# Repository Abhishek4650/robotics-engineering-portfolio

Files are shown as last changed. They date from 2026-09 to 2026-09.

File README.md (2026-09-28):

# Robotics Engineering Portfolio — Abhishek Ray

**6-DOF robot arms: from the kinematics maths, to a mechanical design, to servos moving on a real bus.**

ROS 2 Jazzy · Python · analytical kinematics · parametric CAD · embedded serial-bus servos

I build the whole stack rather than gluing libraries together: the forward kinematics,
Jacobian and IK solvers here are derived and implemented from first principles, then
**verified numerically** against an independent library and against the URDF itself.

---

## Project 1 — Sine-wave trajectory tracing on a myCobot 280

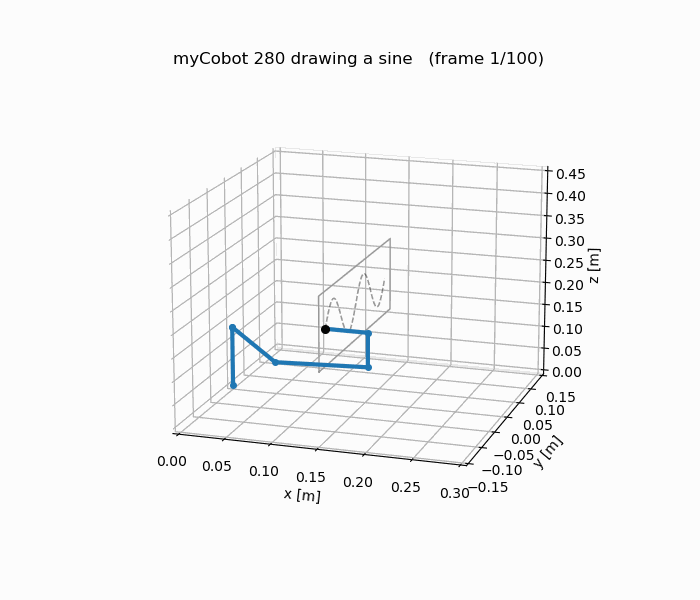
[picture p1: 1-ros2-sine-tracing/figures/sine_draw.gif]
myCobot 280 tracing a sine wave in RViz


A ROS 2 package that drives a 6-DOF arm along a sine wave on a surface, holding the pen
**normal to that surface** throughout.

| | |
| --- | --- |
| **Kinematics** | Modified (Craig) DH forward kinematics, written from scratch |
| **Jacobian** | Velocity propagation, link by link |
| **IK** | Damped least squares, with a tuned damping sweep |
| **Verification** | FK matches the URDF to **~1e-15 m**; Jacobian matches finite differences to **2.5e-7**; cross-checked against `ikpy` |
| **Runtime** | Precomputed trajectory streamed to `/joint_states` at 30 Hz; `robot_state_publisher` → TF → RViz |
| **Feedback** | A second node accumulates the *actually drawn* line from TF, so target (green) and achieved (red) are visible side by side |

→ [`1-ros2-sine-tracing/`](1-ros2-sine-tracing) · [package README](1-ros2-sine-tracing/README.md)

**Why it's not trivial:** a naive IK solution flips the wrist mid-stroke or drifts off the
plane. Constraining the tool orientation while tracking a moving Cartesian target is where
the DLS damping term and the seeding strategy actually matter.

---

## Project 2 — ARM-450: a clean-sheet 6-DOF arm, designed to a hard mass budget

*The first concept. Its successor, rev I.1, the version sent to the printer, is
[Project 6](#project-6--arm-450-rev-i1-the-printable-arm-verified-part-against-part).*

<p align="center">
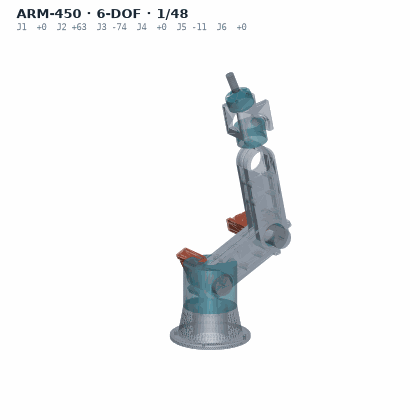
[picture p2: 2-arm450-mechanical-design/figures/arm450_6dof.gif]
ARM-450 six degrees of freedom

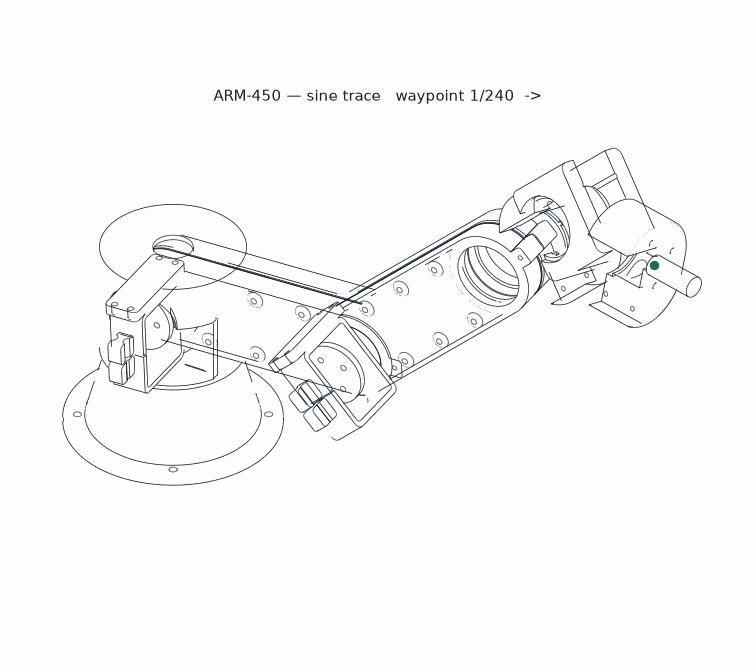
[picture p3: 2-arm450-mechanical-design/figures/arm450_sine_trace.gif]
ARM-450 tracing a sine

</p>

A complete arm designed from nothing — geometry, structure, bearings, fasteners, thermals,
print plan — driven entirely by **parametric Python**, not by hand-modelling in a GUI.
Every dimension comes from `design_params.py`; the URDF, the STEP/STL exports, the
drawings and the reports all regenerate from it.

| Requirement | Result |
| --- | --- |
| Overall length ≤ 450 mm | **450.0 mm** |
| Mass ≤ 1450 g | **1365 g** (85 g headroom) |
| Degrees of freedom | **6**, all with real, sourced hardware |
| Horizontal reach | 360 mm |
| Reachable workspace | **190 litres**, no dead zone |
| Printed parts | 19 pieces, 624 g |
| Sine tracing on the design | **240/240 waypoints, 0.014 mm RMS, 0 collisions** |
| Pre-print gate | **60 checks passed, 0 warnings, 0 failures** |
| STEP B-rep geometry audit | **52 features verified, 0 outstanding** |

**Engineering done here:** joint bearing selection and clearance fits, stress and FEA runs,
compliance budget, creep/fatigue check, servo thermal analysis, interference and mate
checking on the real B-rep, topology and geometry optimisation, slicing/print planning,
and a full bill of materials with sourcing.

The audit caught three defects that would each have wasted a print run — including three
bearing seats that did not physically exist in the solid.

**It is not only drawings — the arm runs.** [`ros2/arm450_description`](2-arm450-mechanical-design/ros2/arm450_description)
is the generated URDF plus meshes, and [`ros2/arm450_sine`](2-arm450-mechanical-design/ros2/arm450_sine)
drives the sine trajectory on it: the design is loaded into ROS 2 and moved, so the geometry
is checked by simulation and not only by the drawings that produced it.

→ [`2-arm450-mechanical-design/`](2-arm450-mechanical-design) ·
[Summary](2-arm450-mechanical-design/SUMMARY.md) ·
[Full report](2-arm450-mechanical-design/REPORT.md) ·
[Drawings](2-arm450-mechanical-design/output) ·
[BOM](2-arm450-mechanical-design/BUY.md)

---

## Project 3 — Hardware bring-up: ESP32 + STS3215 serial-bus servos

Getting a real arm to move, working up from a dead bus.

- **Read-only diagnostics first.** [`scs_diag.py`](3-hardware-esp32-servo/arm_demo/scs_diag.py)
  pings each servo ID and dumps registers using only `PING` and `READ` — no motion command
  is issued until the bus is understood.
- **Protocol reverse-engineering.** Determines the servo family (SC vs ST) from the model
  register, because the two families differ in **units and endianness**; getting this wrong
  drives joints to the wrong angle.
- **Opening the port without resetting the board.** The ESP32 resets on DTR/RTS pulse, which
  drops it out of `SERIAL_FORWARDING` mode — so the port is opened with those lines
  suppressed. This was the actual blocker that stopped the arm moving.
- **Then motion:** single-joint moves, continuous oscillation with logged runs, and finally
  the same sine trajectory from Project 1 streamed to the physical arm.

Stack: Waveshare ESP32 driver board → USB `SERIAL_FORWARDING` bridge → 1 Mbps servo bus → STS3215 servos.

→ [`3-hardware-esp32-servo/`](3-hardware-esp32-servo) · [operating guide (PDF)](3-hardware-esp32-servo/robotic_motion/Robotic_Motion_Guide.pdf) · [run logs](3-hardware-esp32-servo/robotic_motion/logs)

---

## Project 4 — myCobot RViz demo (earlier iteration)

The first working version: offline `ikpy` IK over the official M5 URDF, streamed as
`/joint_states` for RViz. Kept because it shows the progression from *using* an IK library
to *writing* the solver in Project 1.

→ [`4-mycobot-rviz-demo/`](4-mycobot-rviz-demo)

---

## Project 5 — How I got here: the ROS 2 learning progression

I started ROS 2 from zero. The six packages that led to Project 1 are kept **in order and
unedited** — publisher/subscriber, forward kinematics, a first sine attempt, a rewrite after
that attempt drifted, a modular restructure, then the verified solver.

Steps 3 and 4 exist because step 3 was wrong: the arm drifted off the plane, so I wrote a
separate FK test to isolate whether the fault was in the kinematics or the solver. It was in
the kinematics. The 1e-15 m agreement in the finished package is a direct consequence.

→ [`5-ros2-learning-progression/`](5-ros2-learning-progression)

---

## Project 6 — ARM-450 rev I.1: the printable arm, verified part against part

<p align="center">
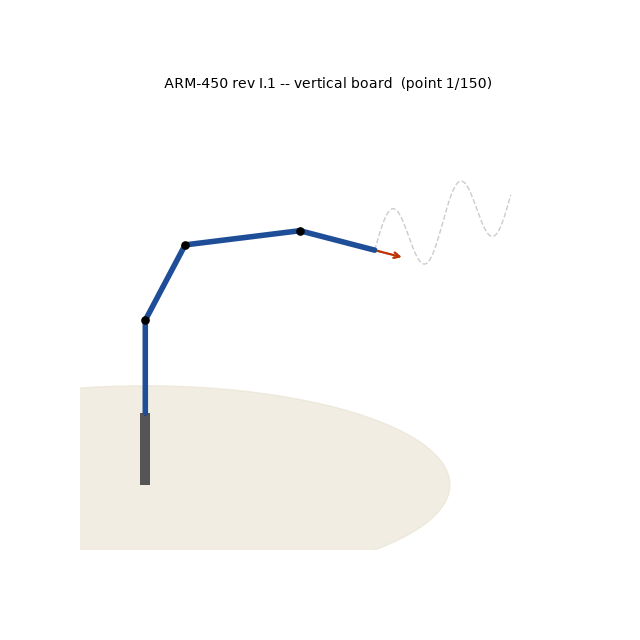
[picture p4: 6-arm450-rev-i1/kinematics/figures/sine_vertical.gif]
ARM-450 rev I.1 tracing a sine on a board

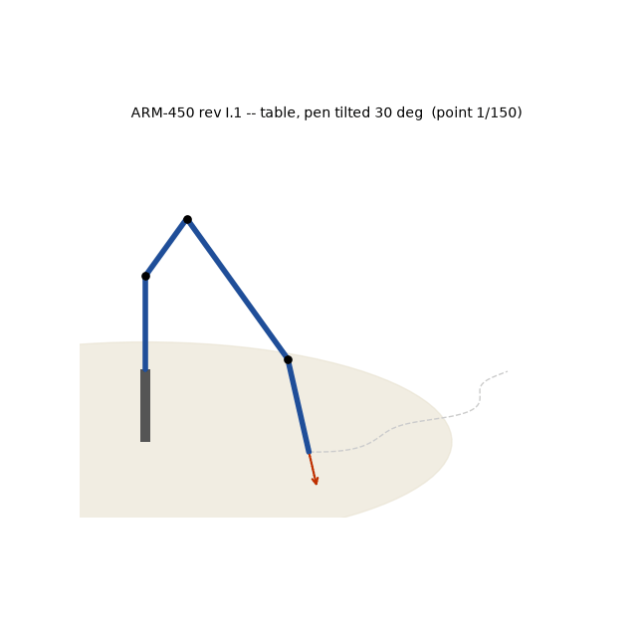
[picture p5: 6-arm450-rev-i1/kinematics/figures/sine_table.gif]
ARM-450 rev I.1 tracing a sine on a table

</p>

The second generation of ARM-450, released for printing: six ST3215 servos, 27 print files
(33 pieces) and 114 screws. The whole release is checked **on the exported 3D geometry**:

- parts may touch only on designed faces, and any other overlap is measured as a boolean volume;
- the official servo model, bearings and every fastener are modelled as solids;
- a hex key must reach every screw at its build step;
- every servo must come out, and every bus plug must go in, with the arm assembled;
- each joint has a proven cable route;
- every glued feature must join over its full section.

All 25 check stages are at 0 failures, and each has its own log.

| | |
| --- | --- |
| **Release** | STL print set + fit-test coupons, STEP parts and assembly, URDF, a Fusion 360 script per part (editable timeline → `.f3d`), SolidWorks macro, 24-step base-to-flange assembly guide |
| **Kinematics** | DH table **derived from the servo axes measured on the CAD**; FK = CAD = URDF to 3e-13 mm; closed-form Pieper IK (8 branches, 0.18 ms) vs DLS / pinv / J-transpose / LM / ikpy |
| **Workspace finding** | The pen can never point straight down: J2 + J3 + J5 give 172.5° of pitch, not 180°. On a table the pen must tilt. |
| **Timing** | Resolved-rate tracking of a 5-D pen task, with the free roll used in the null space; board sine at ~82 mm/s with the servos at half their rating; encoder floor ~0.9 mm |
| **Status** | Print verdict GREEN from the CAD checks; not yet built and measured |

→ [`6-arm450-rev-i1/`](6-arm450-rev-i1) · [README](6-arm450-rev-i1/README.md) ·
[audit report](6-arm450-rev-i1/release/PDF/ARM450_AUDIT_REPORT.pdf) ·
[assembly guide](6-arm450-rev-i1/release/PDF/ARM450_ASSEMBLY_GUIDE_base_to_flange.pdf) ·
[kinematics report](6-arm450-rev-i1/kinematics/docs/ARM450_KINEMATICS.pdf)

---

## Videos

Screen recordings from the work itself, in date order ([`videos/`](videos), with a table of
what each one shows):

- **June 2026, myCobot 280:** first Gazebo and RViz sessions, the end-effector path display,
  the first sine-wave IK node driving Gazebo and RViz together, a joint-trajectory sender,
  and the ikpy demo streaming at 30 Hz.
- **August 2026, ARM-450 first design:** the sine traced in RViz on an early simplified model
  and on the detailed meshes, plus a print timelapse of the J2 turret.

---

## Skills, concretely

| Area | Evidence |
| --- | --- |
| **ROS 2** (Jazzy) | Custom packages, launch files, nodes, TF, `robot_state_publisher`, RViz config, colcon |
| **Robot kinematics** | Modified-DH FK, velocity-propagation Jacobian, DLS / pseudoinverse / Jacobian-transpose / Levenberg–Marquardt IK, manipulability and conditioning |
| **Python** | NumPy, SciPy, matplotlib, ReportLab, PyBullet, `ikpy`, `pyserial` |
| **Mechanical design** | Parametric CAD in code (CadQuery / OpenCascade, Fusion 360 API), STEP/STL export, bearing fits, tolerance and compliance budgets, FEA, DFM for FDM printing |
| **Embedded / hardware** | Serial bus protocols, register-level servo control, ESP32 bridges, systematic bring-up and fault isolation |
| **Verification** | Numerical cross-checking against independent implementations; boolean-volume interference, fastener-access, disassembly and cable-route checks on the real B-rep before printing |
| **Documentation** | Every project ships a README, a generated PDF report, and reproducible figure scripts |

---

## Running any of it

```bash
# ROS 2 Jazzy on Ubuntu
mkdir -p ~/ws/src && cp -r 1-ros2-sine-tracing ~/ws/src/Rsine
cd ~/ws && colcon build --symlink-install && source install/setup.bash
ros2 launch Rsine sine_draw.launch.py
```

Hardware and design scripts are plain Python — see each folder's README.

---

**Abhishek Ray** — Junior Research Fellow, Space Dynamics and Flight Control Laboratory
(SDFCL), Department of Aerospace Engineering, IIT Kanpur · royabhishek4650roy@gmail.com

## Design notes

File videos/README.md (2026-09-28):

# Videos: screen recordings and a print timelapse

These videos run in date order. They follow the work from the first Gazebo and RViz sessions
with the myCobot 280 to the ARM-450 design tracing a sine, and then to printed parts.

The screen recordings are cropped to the Gazebo and RViz windows, so the desktop does not
show. The long 30 June session is cut to 60 seconds. Nothing inside the windows is changed.

## myCobot 280: learning ROS 2 simulation (June 2026)

| Video | What it shows | Project |
|---|---|---|
| [2026-06-25_gazebo_rviz_mycobot_sim.mp4](2026-06-25_gazebo_rviz_mycobot_sim.mp4) | myCobot 280 in a Gazebo Sim scene with objects (left), with the same arm in RViz (right) | [5](../5-ros2-learning-progression) |
| [2026-06-25_gazebo_rviz_mycobot_gripper_scene.mp4](2026-06-25_gazebo_rviz_mycobot_gripper_scene.mp4) | The arm with its gripper moving in Gazebo and RViz, next to a box in the scene | [5](../5-ros2-learning-progression) |
| [2026-06-26_rviz_mycobot_end_effector_path.mp4](2026-06-26_rviz_mycobot_end_effector_path.mp4) | RViz Path displays: the end-effector path (red) and a joint path (green) drawn as the arm moves | [5](../5-ros2-learning-progression) |
| [2026-06-26_rviz_gazebo_sine_ik_paths.mp4](2026-06-26_rviz_gazebo_sine_ik_paths.mp4) | The first sine-wave IK node (`mycobot_sine_wave_ik`) driving RViz and Gazebo together; the red trail records every tool position | [5](../5-ros2-learning-progression) |
| [2026-06-26_gazebo_rviz_sine_ik_sync.mp4](2026-06-26_gazebo_rviz_sine_ik_sync.mp4) | The same node, RViz and Gazebo in step | [5](../5-ros2-learning-progression) |
| [2026-06-27_gazebo_rviz_trajectory_sender.mp4](2026-06-27_gazebo_rviz_trajectory_sender.mp4) | A `trajectory_sender` node streaming joint commands, logged in the terminal, to Gazebo and RViz (2 min) | [5](../5-ros2-learning-progression) |
| [2026-06-29_rviz_mycobot_gripper.mp4](2026-06-29_rviz_mycobot_gripper.mp4) | Close-up of the arm with its gripper in RViz | [5](../5-ros2-learning-progression) |
| [2026-06-29_rviz_mycobot_with_stand.mp4](2026-06-29_rviz_mycobot_with_stand.mp4) | The arm moving beside a stand fixture in RViz | [5](../5-ros2-learning-progression) |
| [2026-06-30_rviz_mycobot_ikpy_sine_60s.mp4](2026-06-30_rviz_mycobot_ikpy_sine_60s.mp4) | The ikpy demo: 238 precomputed frames streamed at 30 Hz to `robot_state_publisher` and RViz (60 s of a 19.5 min run) | [4](../4-mycobot-rviz-demo) |

## ARM-450, first design (August 2026)

| Video | What it shows | Project |
|---|---|---|
| [2026-08-20_rviz_arm450_design_sine.webm](2026-08-20_rviz_arm450_design_sine.webm) | The ARM-450 design tracing a sine (yellow) in RViz | [2](../2-arm450-mechanical-design) |
| [2026-08-21_rviz_arm450_first_model_sine.mp4](2026-08-21_rviz_arm450_first_model_sine.mp4) | An early simplified ARM-450 model tracing the same sine | [2](../2-arm450-mechanical-design) |
| [2026-08-22_rviz_arm450_detailed_model_sine.webm](2026-08-22_rviz_arm450_detailed_model_sine.webm) | The detailed ARM-450 meshes (servos, links, turret) tracing the sine | [2](../2-arm450-mechanical-design) |
| [2026-08-28_print_timelapse_arm450_j2_turret.mp4](2026-08-28_print_timelapse_arm450_j2_turret.mp4) | 3D-print timelapse of the first-design J2 turret, printed spigot-up on tree supports | [2](../2-arm450-mechanical-design) |

More ARM-450 motion, as GIFs: [the first design](../2-arm450-mechanical-design/figures) and
[rev I.1 tracing on a board and on a table](../6-arm450-rev-i1/kinematics/figures).

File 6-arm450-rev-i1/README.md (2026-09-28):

# ARM-450 rev I.1 — the printable arm, verified part against part, with its kinematics

<p align="center">
ARM-450 rev I.1 CAD tracing a sine on a vertical board
ARM-450 rev I.1 CAD tracing a sine on a table
</p>

The second generation of ARM-450 (the first concept is [Project 2](../2-arm450-mechanical-design)).
Rev I.1 is the version sent to the printer: six ST3215 serial-bus servos, 27 print files
(33 pieces), 114 screws, bearings on every joint, and a full kinematic model derived from the
CAD itself.

Every claim below comes from a check run on the **exported 3D geometry**, not from the
parameters used to draw it. Each check has its own log in [`release/LOGS`](release/LOGS).

## What is in this folder

| Folder | Contents |
| --- | --- |
| [`release/`](release) | The rev I.1 release, as released on 2026-09-27: PDFs, print files, editable CAD, logs |
| [`release/PRINTABLE_FILES`](release/PRINTABLE_FILES) | 27 STL files (33 pieces) and a 7-coupon fit test to print first |
| [`release/EDITABLE_CAD`](release/EDITABLE_CAD) | STEP parts and assembly, Fusion 360 joints script, SolidWorks macro, URDF |
| [`release/FUSION_DESIGN_TREES`](release/FUSION_DESIGN_TREES) | One Fusion 360 script per part; each builds the part as an editable timeline and saves the `.f3d` |
| [`release/PDF`](release/PDF) | Audit report, base-to-flange assembly guide (24 steps), fastener manual, poses, part sheets, interface sections |
| [`kinematics/`](kinematics) | DH table, FK, closed-form and numerical IK, Jacobian, workspace, manipulability, timed sine trajectories, ROS 2 demo |
| [`source/`](source) | The generators and verification scripts that produced the release (CadQuery / OpenCascade) |

Start with [`release/READ_ME_FIRST.txt`](release/READ_ME_FIRST.txt), then
[`release/PDF/ARM450_AUDIT_REPORT.pdf`](release/PDF/ARM450_AUDIT_REPORT.pdf).

## The mechanical design

| | |
| --- | --- |
| Actuators | 6 × Waveshare ST3215 serial-bus servos, each screwed to the previous link by its own back holes |
| Drive | Servo horn bolted to the driven link; the joint rides on a ball bearing coaxial with the servo shaft |
| Shoulder load | Gravity springs on J2 and J3; torque safety factor 1.07 (J2) and 1.26 (J3) with the arm level, no payload |
| Mass | 1509 g (printed parts at 65 % infill + 6 servos) |
| Print set | 27 files, 33 pieces; a fit-test coupon confirms the servo screw pattern before the housings are printed |

**Release checks, all at 0 failures** (25 check stages in
[`REVI_CHECKS.log`](release/LOGS/REVI_CHECKS.log)):

- **Mating, not overlapping.** Parts touch only on designed faces, such as bearing seats, the
  horn face and screws in their holes. Any other overlap is measured as a boolean volume and
  fails the check.
- **Real hardware in the assembly.** The official ST3215 model, bearings and every fastener
  are modelled as solids and tested against every part.
- **Buildability.** A hex key reaches all 114 screws at their build step. Every servo can be
  removed, and every servo plug can be inserted with the arm assembled.
- **Cable routing.** Each joint has a proven cable route; no joint turns more than 180°, so
  no cable winds up.
- **Six working joints.** Each servo axis coincides with its bearing axis, the Jacobian has
  rank 6, and the only singularities are the textbook ones.
- **Printability.** Every glued feature joins over its full section. Rev I.1 exists because
  of this check: the J3 spring lugs sat on a 0.1 mm sliver, now 136 mm²
  ([picture](release/PDF/RULE6_VIEWS/j3_lug_fix.png)).
- **Parameters.** 265 design parameters are checked against the geometry they produced.

**Status.** The print verdict is GREEN from the CAD checks. The arm has not yet been built
and measured, so nothing here claims hardware performance.

## The kinematics ([`kinematics/`](kinematics))

The method is modified (Craig) DH, `^{i-1}_iT = Rot_x(α_{i-1}) Trans_x(a_{i-1}) Rot_z(θ_i) Trans_z(d_i)`,
with a velocity-propagation Jacobian: the same method as Project 1. The DH table is
**derived from the servo axes measured on the CAD**, not typed in.

| i | α_{i-1} | a_{i-1} (mm) | d_i (mm) |
|---|---|---|---|
| 1 | 0 | 0 | 90.000 |
| 2 | −90° | 0 | 0 |
| 3 | 0 | 119.000 | 0 |
| 4 | +90° | 0 | 221.369 |
| 5 | −90° | 0 | 0 |
| 6 | +90° | 0 | 0 |

The tool frame is 88.089 mm beyond the wrist centre. J4, J5 and J6 meet at one point, so
the arm has a spherical wrist.

| Result | Value |
| --- | --- |
| FK vs the CAD (product of exponentials of the measured axes) | max 3.0e-13 mm over 2000 poses |
| FK vs the URDF (ikpy) | max 2.6e-13 mm |
| Closed-form IK (Pieper, 8 branches) | 100 % of 500 poses, 0.18 ms, exact |
| Numerical IK from a nearby seed | DLS 95 %, pseudoinverse 99 %, Levenberg–Marquardt 99.8 % |
| Numerical IK from the ready pose | 18–48 %: these solvers are local, so they are used along paths, seeded by the closed form |
| Reach from the J1 axis | 405.5 mm |
| Pen straight down | **Impossible anywhere.** The pitch joints give 54 + 72 + 46.5 = 172.5°, not 180°. On a table the pen must tilt 15° or more. |
| Sine on a vertical board, timed | ~82 mm/s with the servos at half their no-load rating; the encoder alone limits accuracy to ~0.9 mm |

The design lesson: **the joint limits, not the link lengths, decide what this arm can
draw**. Report: [`kinematics/docs/ARM450_KINEMATICS.pdf`](kinematics/docs/ARM450_KINEMATICS.pdf) ·
slides: [`kinematics/docs/ARM450_KINEMATICS_slides.pptx`](kinematics/docs/ARM450_KINEMATICS_slides.pptx).

## Running it

```bash
cd kinematics && bash run_all.sh                 # every analysis, figure, log and the PDF
source /opt/ros/jazzy/setup.bash
cd kinematics/ros2 && ros2 launch sine_demo.launch.py which:=vertical    # or table
```

The scripts in [`source/`](source) are included as they were run. They read the CAD
inputs from the author's workspace by absolute path, so they document the method but do
not run outside that workspace. The released outputs they produced are in `release/`.

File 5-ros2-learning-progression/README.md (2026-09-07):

# How I learned ROS 2 — the working record

I started ROS 2 from zero. These are the packages I built on the way to the verified
solver in [`1-ros2-sine-tracing`](../1-ros2-sine-tracing), kept **in order and unedited**,
because the path matters as much as the destination.

| # | Package | What I was learning | What it does |
| --- | --- | --- | --- |
| 1 | [`my_first_pkg`](my_first_pkg) | The ROS 2 graph | A publisher and a subscriber. Nodes, topics, `setup.py`, `colcon build` — day one. |
| 2 | [`fk_robot`](fk_robot) | Forward kinematics | First transform chain: joint angles → end-effector pose, and checking it against the URDF instead of trusting it. |
| 3 | [`R_sine`](R_sine) | Closing the loop | First attempt at the real task — a sine path, an IK node, and a path tracer to see what the arm *actually* did. |
| 4 | [`R_sine_2`](R_sine_2) | Debugging my own maths | A rewrite after the first version drifted. Includes the `debug/fk_test.py` I wrote to find out why. |
| 5 | [`mycobot_sine_project`](mycobot_sine_project) | Structure | Split into `jacobian.py`, `ik_solver.py`, `trajectory.py`, `publisher.py` — one responsibility per module, so failures became locatable. |
| 6 | **[`Rsine`](../1-ros2-sine-tracing)** | Verification | The finished package: analytical Jacobian by velocity propagation, DLS IK, and every stage checked numerically against the URDF and against `ikpy`. |

## What the progression shows

Steps 3 and 4 exist because step 3 was wrong. The arm drifted off the plane and I did not
know why, so I wrote a separate FK test to isolate whether the error was in the kinematics
or in the solver. It was in the kinematics.

That is the habit worth showing: when something is off, build the smaller test that tells
you *where* it is off, rather than adjusting numbers until the picture looks right. The
1e-15 m agreement in the final package is a direct consequence of having been burned here.

These packages are kept for the record. **For working code, use
[`1-ros2-sine-tracing`](../1-ros2-sine-tracing)** — it supersedes all of them.

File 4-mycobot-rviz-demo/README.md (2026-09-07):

# myCobot 280 — Sinusoidal End-Effector Path (RViz demo)

Drives the end-effector of an **Elephant Robotics myCobot 280 (M5)** along a
**vertical sine wave** (a wave in the X–Z plane) and visualizes it in **RViz 2**.

Joint angles are computed offline with inverse kinematics (`ikpy`) from the
official `mycobot_280_m5` URDF + meshes, then streamed as `/joint_states`;
`robot_state_publisher` broadcasts TF and RViz renders the moving arm. No MoveIt,
ros2_control, or hardware required — it's a pure visualization/kinematics demo.

EE path

## Requirements

- **ROS 2** (tested on **Jazzy**; Humble should also work) with `rviz2` and
  `robot_state_publisher` (both in a standard desktop install).
- **Python 3.10+** with `venv` (`sudo apt install python3-venv` if missing).
- Internet access on first setup (to `pip install ikpy scipy numpy matplotlib`).

## Setup (one time)

```bash
cd mycobot_280_sine          # this folder
./setup.sh                   # creates ./venv, installs deps, generates local URDF
```

`setup.sh` makes a virtualenv with `--system-site-packages` so it can see ROS's
`rclpy` while also providing `ikpy`. It is safe to re-run.

## Run

```bash
source /opt/ros/jazzy/setup.bash   # use your ROS 2 distro (jazzy / humble / ...)
./run.sh
```

RViz opens with the myCobot 280 tracing the sine wave on a loop. (`run.sh` just
sources the venv and calls `ros2 launch launch/sine_demo.launch.py`.)

## Generate results (optional, no ROS needed)

```bash
. venv/bin/activate
python scripts/generate_results.py   # writes results/ : plots + trajectory.csv
python scripts/preview_path.py       # quick X–Z preview + IK error report
```

## Customizing the wave

Edit the defaults of `make_sine_path(...)` in
[`scripts/kinematics.py`](scripts/kinematics.py):

| param | meaning | default |
|---|---|---|
| `x0`, `x1` | start/end of the forward sweep along X (m) | 0.10, 0.20 |
| `z0` | center height of the wave (m) | 0.18 |
| `amplitude` | wave height (m) | 0.03 |
| `wavelength` | spatial period along X (m) | 0.10 |
| `n_points` | waypoints per sweep | 120 |

Publish rate is `PUBLISH_HZ` in
[`scripts/sine_trajectory_node.py`](scripts/sine_trajectory_node.py).
After changing the path, re-run `generate_results.py` to re-validate reachability
(keep the EE within the arm's ~0.28 m reach and joint limits).

## Layout

```
launch/sine_demo.launch.py   robot_state_publisher + trajectory node + rviz2
rviz/sine.rviz               RViz config (RobotModel + TF, fixed frame g_base)
scripts/kinematics.py        ikpy chain, sine-path generator, IK, FK
scripts/sine_trajectory_node.py  rclpy node publishing /joint_states @ 30 Hz
scripts/make_local_urdf.py   generates machine-local URDF (absolute mesh paths)
scripts/preview_path.py      offline IK/workspace check (matplotlib)
scripts/generate_results.py  result plots + CSV export
urdf/mycobot_280_m5/         official M5 URDF + .dae meshes + textures
urdf/mycobot_280.urdf        simplified fallback URDF (primitive shapes, no meshes)
requirements.txt             Python deps
setup.sh / run.sh            one-command setup / launch
```

## Notes & troubleshooting

- **`mycobot_280_m5_local.urdf` is generated**, not shipped — it holds absolute
  mesh paths for *your* machine and is created by `setup.sh` (and auto-regenerated
  by the scripts/launch). This is what makes the package relocatable.
- **ikpy warnings** at startup (`fixed ... axis attribute`, `Base link ... set as
  active`) are harmless — they refer to the non-moving base frames and don't
  affect the kinematics.
- **Arm not visible / no meshes**: ensure `setup.sh` finished and that you sourced
  ROS 2 before `./run.sh`. Re-generate the URDF with
  `python scripts/make_local_urdf.py`.
- **Model credit**: URDF + meshes are from Elephant Robotics'
  [`mycobot_ros2`](https://github.com/elephantrobotics/mycobot_ros2)
  (`mycobot_description`).

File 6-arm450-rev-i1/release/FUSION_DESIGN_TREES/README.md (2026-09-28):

# ARM-450 rev I — Fusion 360 design trees, one script per part

Every printed part of the arm (27) and the 7 fit-test coupons, each as a **Fusion 360 script
that builds the part as an editable parametric design** — a timeline of sketches, extrudes,
lofts, combines (join / cut / intersect), fillets and chamfers — and **saves it as `.f3d`**.

| folder | what is in it |
|---|---|
| `00_BUILD_ALL_f3d/` | **one script that builds every part and saves each `.f3d`** (run this once) |
| `parts/NN_part_xQ/` | one folder per part: `NN_part_xQ.py` (the script), `.manifest`, `.json` (its feature list), `_released.step` (the released solid, to compare) |
| `fit_test/fit_0N_…/` | the same for the 7 fit-test coupons |
| `tools/` | how these were made (recorder, unfolder, script writer, the offline check) |
| `VERIFY_MOCK_FUSION.log` | the offline check of every script against the released STEP |

## Why a script and not the `.f3d` file itself

`.f3d` is Autodesk's own archive format: only Fusion 360 can write it. This machine has no
Fusion, so the `.f3d` files are made **by Fusion on your computer** — run the script once and
the `.f3d` appears in the part's folder, next to the script.

## Run

1. Fusion 360 → **UTILITIES → ADD-INS → Scripts and Add-Ins** (Shift+S) → **Scripts** tab.
2. Click the green **+** next to *My Scripts* → pick the folder `00_BUILD_ALL_f3d`
   (or one part's folder) → select it → **Run**.
3. Each part opens as a new design, is built feature by feature, checked against the released
   part (volume + bounding box; the report says `MATCHES THE RELEASED PART` or `CHECK`), saved as
   `parts/NN_part_xQ/NN_part_xQ.f3d` with a `_BUILD_REPORT.txt`, and closed (BUILD ALL) or left
   open (single part). `00_BUILD_ALL_f3d/BUILD_ALL_REPORT.txt` lists every part.

## Edit

Open a part's `.f3d` (File → Open → *Open from my computer*). The timeline at the bottom is the
design tree:

* **Sketch → Extrude / Loft** — double-click the sketch to change its lines and circles,
  double-click the extrude to change its distance.
* **Combine** — join / cut / intersect exactly as the generator did it; edit or suppress one to
  add back or remove material.
* **Fillet / Chamfer** — edit the radius / distance.
* **Move** — follows the extrude of a body that is not square to the XY plane (it is sketched on
  XY and moved into place).
* Every item is named `NNNN <what> <generator function> L<line>` — the line of the ARM-450 generator
  (`REV_H/*.py`, `arm450_design/…`) that made it; the timeline is grouped by generator function.

The parts are built in the arm's **design frame** (the released STEP frame, mm), not in print
orientation — the print orientation of each part is in `../PRINTABLE_FILES` / the print list.

## Results (rev I.1, 2026-09-27)

* **34 parts, 1616 features** (rev I.1: `12_J3_p1` now carries the sunk spring lugs with R3 webs).
  Every recorded solid equals its released STEP (largest difference 0.006 mm³, `10_link_upper_tongue` —
  see the note below).
* **Offline rebuild: 34 / 34 match** the released STEP (largest difference 0.006 mm³), in both
  readings of Fusion's rules: `VERIFY_MOCK_FUSION.log` (Fusion accepts a cut tool that misses the
  body and a join of bodies that do not touch) and `VERIFY_MOCK_FUSION_STRICT.log` (it refuses
  them — the scripts then cut tool by tool and join pair by pair).
* `00_BUILD_ALL_f3d` was run the same way offline: 34 parts, 0 to check.

| part | print | features | of which | recorded vs released (mm³) | mock-Fusion timeline items | mock rebuild vs released (mm³) |
|---|---|---|---|---|---|---|
| `01_base_x1` | 1 | 33 | 14 combine, 13 extrude, 1 fillet, 5 loft | 0.0000 | 65 | 0.0000 OK |
| `02_spigot_collar_x1` | 1 | 17 | 8 combine, 9 extrude | 0.0000 | 30 | 0.0000 OK |
| `03_j1_mount_x1` | 1 | 106 | 45 combine, 61 extrude | 0.0000 | 200 | 0.0000 OK |
| `04_j1_hub_x1` | 1 | 26 | 12 combine, 1 chamfer, 13 extrude | 0.0000 | 39 | 0.0000 OK |
| `05_J2_turret_p1_x1` | 1 | 93 | 46 combine, 43 extrude, 4 loft | 0.0000 | 171 | 0.0000 OK |
| `06_J2_turret_p2_x1` | 1 | 114 | 49 combine, 63 extrude, 2 loft | 0.0000 | 267 | 0.0000 OK |
| `07_J2_shaft_x1` | 1 | 18 | 8 combine, 1 chamfer, 9 extrude | 0.0000 | 36 | 0.0000 OK |
| `08_shaft_clamp_x4` | 4 | 9 | 4 combine, 5 extrude | 0.0000 | 16 | 0.0000 OK |
| `09_link_upper_groove_x1` | 1 | 65 | 31 combine, 32 extrude, 2 fillet | 0.0000 | 105 | 0.0000 OK |
| `10_link_upper_tongue_x1` | 1 | 81 | 39 combine, 40 extrude, 2 fillet | 0.0061 | 130 | 0.0062 OK |
| `11_collar_upper_x2` | 2 | 13 | 6 combine, 7 extrude | 0.0000 | 23 | 0.0000 OK |
| `12_J3_p1_x1` | 1 | 135 | 65 combine, 67 extrude, 1 fillet, 2 loft | 0.0000 | 227 | 0.0000 OK |
| `13_J3_p2_x1` | 1 | 146 | 63 combine, 81 extrude, 1 fillet, 1 loft | 0.0004 | 271 | 0.0004 OK |
| `14_J3_shaft_x1` | 1 | 18 | 8 combine, 1 chamfer, 9 extrude | 0.0000 | 27 | 0.0000 OK |
| `15_link_fore_tongue_x1` | 1 | 81 | 39 combine, 40 extrude, 2 fillet | 0.0000 | 129 | 0.0000 OK |
| `16_link_fore_groove_x1` | 1 | 85 | 41 combine, 42 extrude, 2 fillet | 0.0000 | 135 | 0.0000 OK |
| `17_collar_fore_x2` | 2 | 13 | 6 combine, 7 extrude | 0.0000 | 23 | 0.0000 OK |
| `18_j4_base_x1` | 1 | 61 | 29 combine, 32 extrude | 0.0000 | 96 | 0.0000 OK |
| `19_j4_cap_x1` | 1 | 23 | 11 combine, 12 extrude | 0.0000 | 35 | 0.0000 OK |
| `20_j4_hub_x1` | 1 | 31 | 15 combine, 16 extrude | 0.0000 | 47 | 0.0000 OK |
| `21_J5_p1_x1` | 1 | 97 | 46 combine, 48 extrude, 1 fillet, 2 loft | 0.0000 | 162 | 0.0000 OK |
| `22_J5_p2_x1` | 1 | 140 | 60 combine, 78 extrude, 1 fillet, 1 loft | 0.0004 | 260 | 0.0004 OK |
| `23_J5_shaft_x1` | 1 | 16 | 7 combine, 1 chamfer, 8 extrude | 0.0000 | 24 | 0.0000 OK |
| `24_J5_spacer_x2` | 2 | 1 | 1 extrude | 0.0000 | 2 | 0.0000 OK |
| `25_j6_body_x1` | 1 | 62 | 30 combine, 32 extrude | 0.0000 | 122 | 0.0000 OK |
| `26_j6_cap_x1` | 1 | 23 | 11 combine, 12 extrude | 0.0000 | 47 | 0.0000 OK |
| `27_j6_flange_x1` | 1 | 31 | 15 combine, 16 extrude | 0.0000 | 63 | 0.0000 OK |
| `fit_01_servo_pinch` | 1 | 3 | 1 combine, 2 extrude | 0.0000 | 5 | 0.0000 OK |
| `fit_02_6806_seat` | 1 | 5 | 2 combine, 3 extrude | 0.0000 | 8 | 0.0000 OK |
| `fit_03_6706_seat` | 1 | 5 | 2 combine, 3 extrude | 0.0000 | 8 | 0.0000 OK |
| `fit_04_shaft_stub` | 1 | 5 | 2 combine, 3 extrude | 0.0000 | 8 | 0.0000 OK |
| `fit_05_centring_ring` | 1 | 1 | 1 extrude | 0.0000 | 2 | 0.0000 OK |
| `fit_06_holes` | 1 | 11 | 5 combine, 6 extrude | 0.0000 | 17 | 0.0000 OK |
| `fit_07_servo_screws` | 1 | 48 | 16 combine, 32 extrude | 0.0000 | 113 | 0.0000 OK |

Note — `10_link_upper_tongue`: the released rev-I tongue was made by reading the released upper
link STEP back and measuring its hole centres. Here the upper link is rebuilt by its generator
(`arm450_design/verify_pro/parts/link_pro.py`, `build(tongue=True, end="socket")`, proven equal to
the released STEP: 0.0000 mm³ both ways), so the measured centres differ in the 5th decimal:
0.006 mm³ in all — far below one printed layer.

## How they were made and checked

1. **Recorded** — the release generators were re-run in a scratch copy (nothing in the release
   was written) with every CadQuery modelling call recorded: each extrude with its exact sketch
   (lines, arcs, circles), each loft, boolean, fillet, chamfer and move.
2. **Recorded = released** — each part's recorded solid was compared with the released STEP by
   boolean difference both ways.
3. **Unfolded** into a Fusion timeline — moves and mirrors carried down onto the sketches; cut
   tools that miss the part dropped (they change nothing).
4. **Rebuilt offline** — every emitted script was run against a stand-in for Fusion's API
   (`tools/mock_adsk`, OpenCascade under the same calls) and its result compared with the released
   STEP (`VERIFY_MOCK_FUSION.log`).

What step 4 cannot prove is how Fusion's own kernel evaluates each feature — that is why every
script re-checks its result inside Fusion and says `MATCHES` or `CHECK`. If a part says `CHECK`,
send its `_BUILD_REPORT.txt`.

Rebuild all of this: `python3 tools/make_trees.py && python3 tools/emit_scripts.py && python3 tools/verify_mock.py`.

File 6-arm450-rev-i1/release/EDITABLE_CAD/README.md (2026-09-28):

# ARM-450 rev I -- editable CAD

Everything in this folder was exported from the verified rev-I design (all
release checks at 0, Rule 4 mating check at 0). Units are mm (URDF: m).

## What is here

| folder / file | what | open with |
|---|---|---|
| `parts_step/` | the 27 printed parts, one solid each, STEP AP214 | SolidWorks, Fusion 360, FreeCAD, Onshape, any CAD |
| `assembly_step/ARM450_ASSEMBLY.step` | the whole arm: 7 components, one per moving body (ground, turret, upper_link, forearm, j4_hub, blade, flange), with every part, servo, bearing, screw, insert and spring placed inside | any CAD |
| `assembly_step/body_*.step` | the same 7 bodies as separate files (the Fusion script imports these) | any CAD |
| `fit_test_step/` | the 7 fit-test coupons (print these first), STEP | any CAD |
| `fusion360/ARM450_joints.py` | Fusion 360 script: imports the 7 bodies, grounds the base, creates the 6 revolute joints with their limits, saves a native `.f3d` | Fusion 360 |
| `fusion360/ARM450_import_all.py` | Fusion 360 script: EVERY STEP of `parts_step/`, `fit_test_step/` and `assembly_step/` into its own Fusion design, saved in your project under `ARM450_rev_I/<folder>` and exported as a local `.f3d` in `fusion360/f3d/<folder>/` | Fusion 360 |
| `fusion360_parts/` | 34 individual part script folders (one per printable part + 7 fit test coupons): import and edit any part individually | Fusion 360 |
| `solidworks/ARM450_to_solidworks.swb` | SolidWorks macro: saves every part as `.SLDPRT` and the assembly as `.SLDASM` | SolidWorks |
| `urdf/` | `arm450.urdf` + meshes + `display.launch.py`: drag the 6 joints with sliders in RViz | ROS 2 Jazzy |
| `JOINT_AXES.csv` | each joint: point, axis direction, range (measured on the bearing pockets and servo horns) | spreadsheet |
| `PARAMETERS.csv` | 265 key dimensions: design value vs value measured in the exported file | spreadsheet |

**Native `.sldprt` / `.f3d` files can only be written by SolidWorks / Fusion
themselves.** Run the script or macro once and your CAD program creates them.
Neither script could be run on the build machine (no licence there). If one
stops, its message says where, and the manual steps below do the same thing.

## Fusion 360: individual part scripts (one folder per printable part)

If you only want to inspect or modify one specific part without running the full 41-file import:
1. Utilities > **Scripts and Add-Ins** > Scripts > green **+** > browse to `fusion360_parts/<part_name>` (e.g. `05_J2_turret_p1_x1` or `fit_01_servo_pinch`).
2. Select the part name in the list and click **Run**.
3. If an assembly is open, you can choose to open the part in a **new document** or insert it as a component into your **active design**.
4. Each folder is completely self-contained with its `.py` script, `.manifest`, `.step` CAD model, `.stl` printable file, and `README.md`.

## Fusion 360: every part as its own editable design

Utilities > **Scripts and Add-Ins** > Scripts > green **+** > the `fusion360`
folder > `ARM450_import_all` > **Run**. It takes a few minutes (41 files): each
STEP opens as a new design, is saved in your active project (folders
`ARM450_rev_I/parts_step`, `.../fit_test_step`, `.../assembly_step`) and exported
as a local `.f3d` into `fusion360/f3d/`. The message box at the end lists every
file and whether it worked.

## Fusion 360: an assembly you drag by its joints

1. Utilities > **Scripts and Add-Ins** > Scripts > the green **+** > pick the
   `fusion360` folder > select `ARM450_joints` > **Run**.
2. It imports the seven bodies, grounds `ground`, creates the six **revolute**
   joints (J1 base yaw ... J6 tool roll) with their limits, and saves
   `ARM450_rev_I` in your active project.
3. Grab any link with the pointer and drag it: it turns about its joint only,
   like the revolute-joint preview. Double-click a joint to **Animate** it.

If a joint is reported as failed, make it by hand: **Assemble > Joint**,
type **Revolute**, pick the child body then the parent body, and snap both
to the circle of that joint's bearing pocket. The axes are in
`JOINT_AXES.csv`. Set the limits under **Edit Joint Limits** (range column).

**Editing a part in Fusion:** STEP imports as a solid with no history. Use
**Press Pull** (change a face offset, a hole diameter or a pocket depth),
**Delete** (remove a face or feature: the hole closes up), **Extrude** from
a sketch on a face (add or cut), and **Move/Copy** (reposition faces). To
get a timeline, right-click the body > Capture Design History.

## SolidWorks: `.SLDPRT` + `.SLDASM`

1. Tools > Macro > **Run** > `solidworks/ARM450_to_solidworks.swb`.
2. Every part is saved as `.SLDPRT`, and the assembly as `ARM450_ASSEMBLY.SLDASM`
   with its part files, all in the `solidworks` folder.
3. **Features you can edit:** open a part, then Insert > FeatureWorks >
   **Recognize Features**. Holes, extrudes, cuts and fillets become features
   in the tree with dimensions you can change.
4. **Motion:** in the assembly, float every body except `ground`, then add
   **Concentric** mates on each joint's bearing pocket plus a **Coincident**
   mate on its face. Add a **Limit Angle** mate for the range in
   `JOINT_AXES.csv`. Now drag a link and it rotates about its joint.

(Or File > Open the assembly STEP directly: SolidWorks converts it to an
assembly and parts, and you add the mates as in step 4.)

## ROS 2: drag the joints with sliders

```
source /opt/ros/jazzy/setup.bash
ros2 launch ~/ros2_ws/Arm_450_new_design/EDITABLE_CAD/urdf/display.launch.py
```
RViz opens together with a slider window, one slider per joint. In RViz set
Fixed Frame = `ground` and add a **RobotModel** display (topic
`/robot_description`). The URDF was checked here: `check_urdf` parses it,
its kinematics match the verified joint axes to within 1e-12 mm over 200
random poses, and `robot_state_publisher` loads it. Your existing
`ros2_ws/src/arm450_description` package was **not** touched.

## Changing the design at the source

Every part is generated by a Python (CadQuery) script in `../REV_H/`, where
each dimension is a named parameter at the top of the file. Examples:
`gen_drive_j3.py` (J3 fork), `gen_clamp.py` (link centring ring),
`drive_common.py` (shared: bay, pinch, shaft, flats, split bolts). After a
change, run `../REV_H/release_run.sh`: every check is repeated and the print
files are rebuilt.

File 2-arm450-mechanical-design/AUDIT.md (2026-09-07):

# ARM-450 — Part-by-Part Geometry Audit

**Read from the STEP B-rep, not from the source that made it and not from a mesh.**

> ## STATUS: ALL DEFECTS FIXED — 2026-08-21
>
> **52 features verified present · 0 needing attention.** Nothing had been printed when
> these were found, so every fix went in at the source and every part was regenerated.
> The sections in this document are re-rendered from the corrected geometry: all nine now
> read **POCKET PRESENT**.
>
> | # | part | defect | fix |
> | --- | --- | --- | --- |
> | 1–2 | link halves | no Ø42 bearing pocket | solid boss ring unioned back before counterboring |
> | 3 | base | no Ø42 J1 seat | cable bore now stops below the seat, leaving a Ø38 shoulder |
> | 4 | `wrist_j6_output` | 3 of 4 tool bolts | honest **3-bolt** interface at 160/250/340°, all in material |
> | 5 | `wrist_j5_yoke` | cheek spacing 38.02 | SPAN derived from `BRG_SPACING` → **40.00** |
> | 6 | wrist parts | `horn_pattern()` no-ops | **still open — needs your decision, see §6** |
>
> **Mass went 1143 g → 1191 g.** The boss rings cost 48 g. That is 9 g under the 1.2 kg
> limit — real but very tight, and worth knowing before anything else is added.
>
> The pre-print gate now runs this audit as check 56, so this class of defect cannot pass
> it again.

---

`audit_parts.py` enumerates every cylindrical face in each STEP file, groups the faces into
physical holes, and checks each part against the features it is supposed to have.
`draw_2d_verify.py` then cuts a true section through each bearing interface so every finding
can be confirmed by eye.

---

## Why the pre-print gate did not catch any of this

The gate contains this check:

```python
check(abs((BRG_OD + BRG_FIT) - 42.00) < 1e-6, "bearing pocket Ø42.00", ...)
```

That checks the **parameter**. It confirms two numbers in `params.py` add up to 42.00. It
never opens the part. Every one of the defects below passed that gate 55/55, because in
each case the parameter is perfectly correct and the *geometry* does not contain it.

**A gate that reads the design intent instead of the produced geometry cannot find a
feature that was silently consumed by an earlier cut.** That is the single most useful
thing this audit established, and it is why `audit_parts.py` now exists alongside the gate.

---

## What was found, and what it was

| # | part | defect | severity |
| --- | --- | --- | --- |
| 1 | `link_half_tongue` | no Ø42 bearing pocket | **BLOCKING** |
| 2 | `link_half_groove` | no Ø42 bearing pocket | **BLOCKING** |
| 3 | `base` | no Ø42 J1 bearing seat | **BLOCKING** |
| 4 | `wrist_j6_output` | 3 of 4 tool-face bolt holes | moderate |
| 5 | `wrist_j5_yoke` | cheek spacing 38.02, drawing says 40.00 | minor |
| 6 | all wrist parts | `horn_pattern()` calls are no-ops | needs a decision |

---

### 1 & 2 — The link halves have no bearing pocket

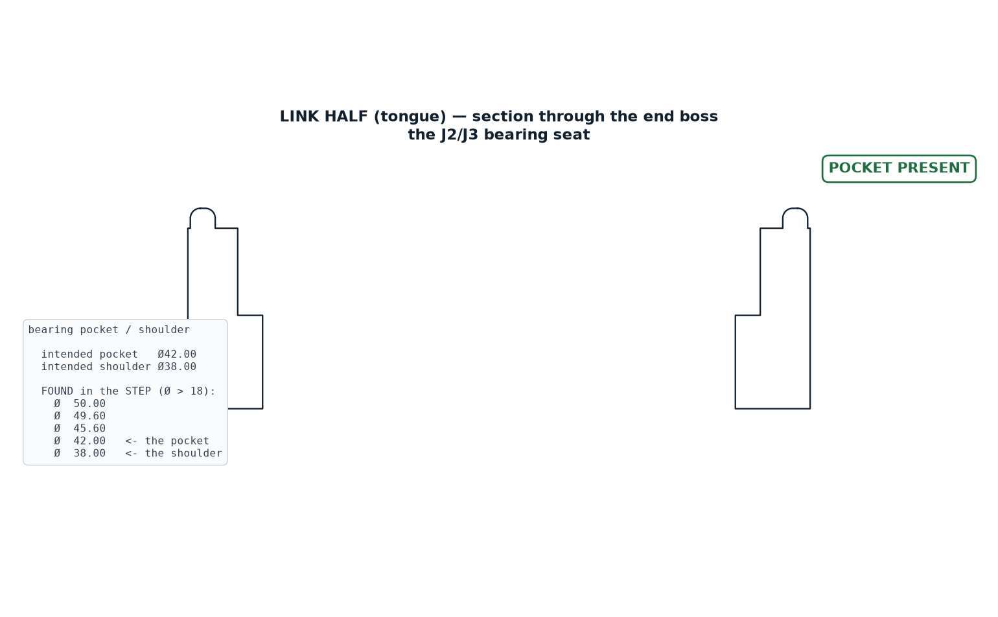
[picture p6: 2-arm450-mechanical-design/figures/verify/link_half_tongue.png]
Link half tongue section


The section is taken straight through the end boss. **There is no counterbore step.** The
wall runs straight from the web to the seam face.

Diameters the STEP actually contains at that boss: **Ø50.00, Ø49.60, Ø45.60, Ø45.20,
Ø38.00.** There is no Ø42.

**Cause.** In `cad/link_shell.py` the shell is hollowed at step 2 and the pocket is cut at
step 3. The hollow uses `boss_r - WALL_FLANGE` = 25 − 2.4 = **Ø45.20** at the end boss.
The pocket cut that follows is Ø42.00 — *smaller than the hole it is cutting into*, so it
removes nothing at all. CadQuery does not complain: cutting a small cylinder out of an
already-empty region is a legal no-op.

**Consequence.** A Ø42.00 bearing dropped into a Ø45.20 bore has **1.60 mm of radial
clearance**. At the 360 mm tool radius that is roughly 20 mm of tool wander — the joint has
no location at all. This is the exact failure the paired-bearing redesign was written to
eliminate, and it has been present in every version of the link.

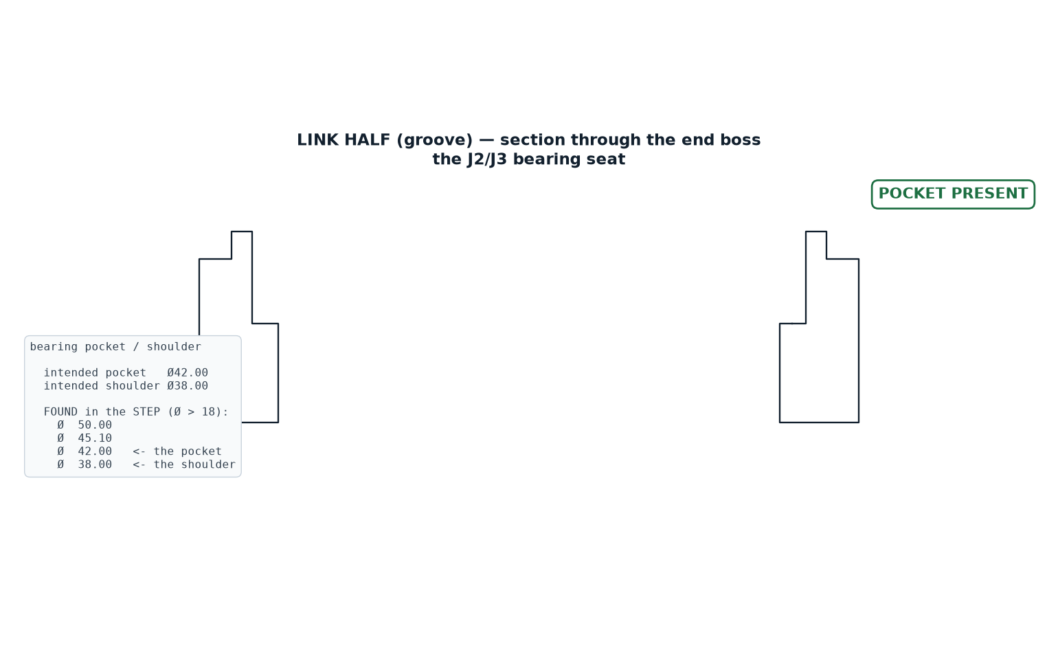
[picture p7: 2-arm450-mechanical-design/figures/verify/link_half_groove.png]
Link half groove section


Identical on the groove half.

---

### 3 — The base has no J1 bearing seat

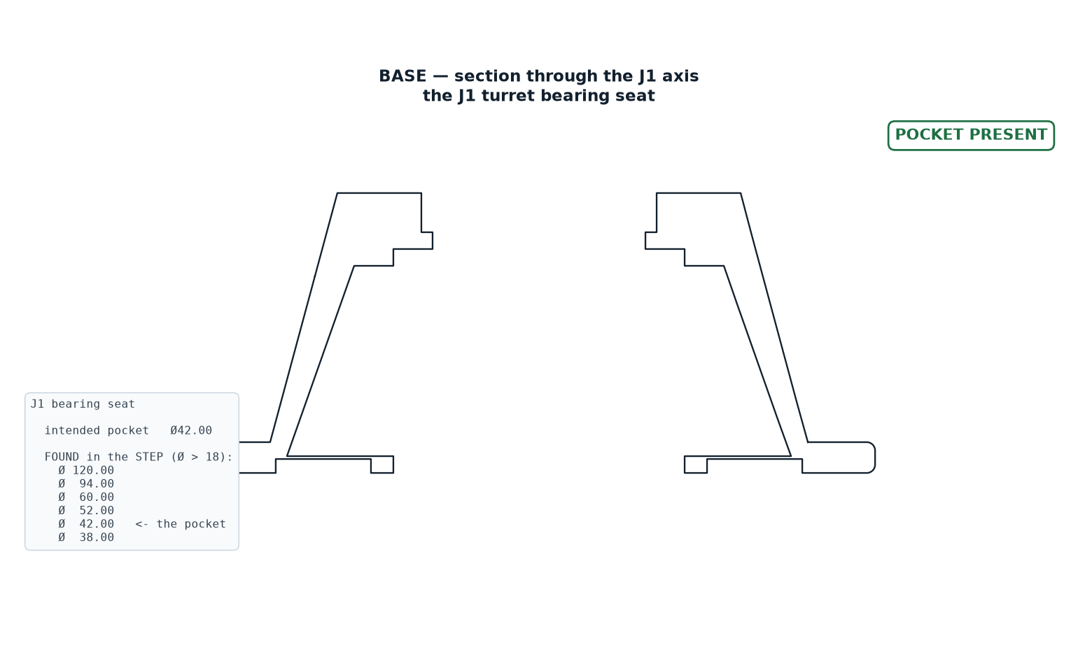
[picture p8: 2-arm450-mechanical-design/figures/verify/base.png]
Base section


Both pedestal walls end in a plain flat rim. There is no step for a bearing to sit in.
Diameters found: **Ø120.00 and Ø52.00**. No Ø42.

**Cause.** In `cad/base_wrist.py`:

```python
b = b.cut(... circle(CABLE_BORE / 2) ...)   # Ø52, straight through
b = b.cut(... circle((BRG_OD + BRG_FIT) / 2) ...)   # Ø42 "seat"
```

The Ø52 cable bore is cut through the full height first. The Ø42 seat is then cut inside a
hole that is already Ø52. **42 < 52, so it removes nothing.**

**Consequence.** The J1 bearing has nothing to seat in — a Ø42 bearing over a Ø52 hole
drops straight through. The whole arm has no defined rotation axis at its base.

---

### 4 — J6 tool face has three bolt holes, not four

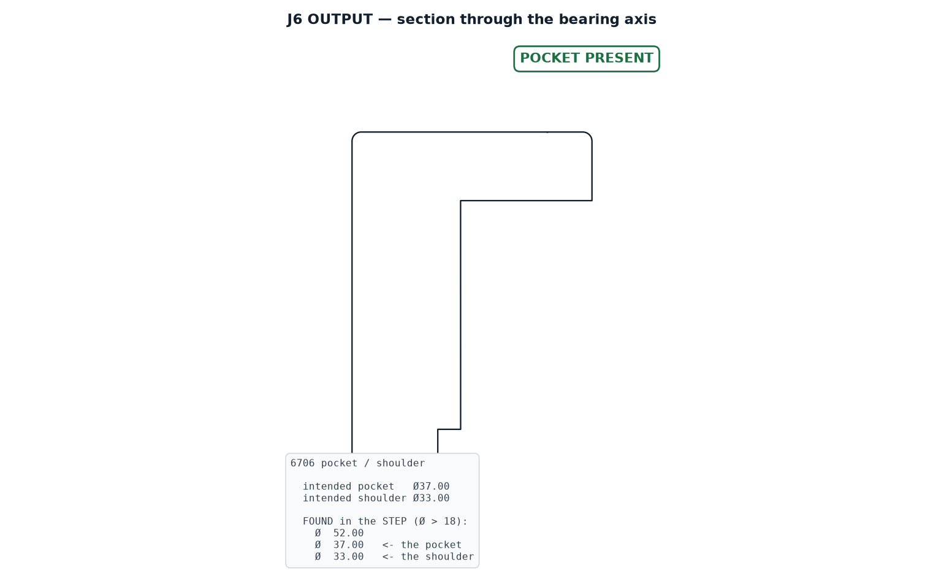
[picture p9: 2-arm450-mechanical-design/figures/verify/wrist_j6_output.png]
J6 output section


Holes found at r = 15.00 (correct, Ø30 BCD): **(−10.61, −10.61), (−10.61, +10.61),
(+10.61, −10.61)**. The fourth, at (+10.61, +10.61), is absent — the servo pocket opening
occupies that quadrant, so there is no material to drill.

The isometric sheet calls out "4 × Ø3.40 ON Ø30.00 BCD". Three of four means a tool bolts
on asymmetrically, and the drawing overstates what is there.

---

### 5 — J5 yoke cheek spacing

Bearing-face spacing measures **38.02 mm**. `BRG_SPACING` is 40.00 and the isometric sheet
says "CHEEK SPACING 40.00". Moment stiffness goes as spacing squared, so 38.02 against
40.00 is a **9.6 % loss of moment stiffness** — small, but the drawing should not claim a
number the part does not have.

---

### 6 — The horn patterns are no-ops

`horn_pattern()` is called on `wrist_j4_housing`, `wrist_j6_output` and `turret_j1`. **None
of the three parts contains a single hole on the Ø14 horn bolt circle.** The pattern is cut
at r = 7.0, which in every case falls inside the Ø38 through bore or the Ø42 pocket —
already-empty space, so again a legal no-op.

This one needs a decision rather than a fix: if the servo body is captured in the pocket
and its horn bolts to the *mating* part, no horn holes are needed here and the calls should
be deleted. If the horn is meant to drive this part, the holes have to move outboard of the
Ø38 bore.

---

## The pattern behind all of it

Every one of these is the same mistake in a different place: **a cut made into a region
that a previous cut had already emptied.** Boolean subtraction of a smaller shape from a
larger void is silent — no error, no warning, no change in volume. It looks exactly like
success.

Three defences now exist:

1. `audit_parts.py` — reads geometry, not intent, and checks that each expected feature is
   physically present at the right size and place.
2. `draw_2d_verify.py` — a section through every bearing interface, so a missing seat is
   visible rather than inferred.
3. `cad/volumes.py` — a single generator for the mass table, so derived numbers cannot go
   stale unnoticed.

**All of findings 1–5 are now fixed and verified.** In each case the fix was ordering:
restore the material before counterboring it, or stop the earlier cut short of the feature
it would otherwise swallow.

Finding 6 is a design decision and is still open — see above.

The durable change is check 56 in `preprint_check.py`: the gate now runs this audit and
fails on any missing feature. Checking the parameter was never going to be enough.

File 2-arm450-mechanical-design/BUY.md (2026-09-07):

# ARM-450 — Purchasing List

- **Date:** 2026-08-20
- **What this covers:** everything that must be **bought**, not printed.
- **Printed parts** are covered separately in `ARM450_DRAWINGS_2D.pdf`.

---

> ## ⚠ READ BEFORE YOU SLICE — 2026-08-23
>
> **0. THE BUILD MATERIAL IS NOW PLAIN PLA**, not carbon-filled — `params.MATERIAL = "PLA"`.
> Every load case was re-run: **10 of 10 pass**, worst-case deflection 0.197 mm against a
> 0.30 mm limit, and backlash still dominates at 2.25 mm so it is invisible at the tool.
> Three things change for the better — **no hardened nozzle needed** (brass is fine), better
> layer adhesion, and the printed structure is **24 g lighter** at 1.24 g/cm³.
> One thing gets worse: plain PLA shrinks **0.40 %** against CF's 0.15 %, which is
> **0.17 mm on a Ø42 bore** — larger than the coupon's whole 0.10 mm bracket.
> **Budget two coupon prints.**
>
> **1. `output/cad/` contains 12 files that must NOT be printed.** Superseded parts
> (`bearing_yoke`, `wrist_yoke_j5`, `roll_module`, `wrist`, `tool_flange`), models of
> bought items (`bearing_6806`, `joint_shaft`, `shaft_tube` — the shaft is an aluminium
> tube), and assembly renders (`arm450_assembly_*`, `arm450_parts_kit`). **Print only the
> 17 files named in the print list below.** `python3 final_audit.py` lists them.
>
> **2. The assembled arm is ~1608 g, not 1365 g.** The mass gate never had a fastener term:
> 40 brass inserts, six M5 × 90 preload bolts and ~100 screws come to **244 g**, and steel
> and brass are 6–7× the density of the plastic they hold. That is **158 g over the 1450 g
> ceiling** and it cannot be closed with fastener substitutions alone (everything
> compatible saves 78 g). This does not affect printing — no printed part changes — but the
> mass requirement is not met. See `mass_options.py`.
>
> **3. The gripper was re-cut on 2026-08-23.** Rack teeth were 1.20 mm deep instead of
> 2.40 (the cutter was centred on the bar face, so half of it cut air), the rack channels
> broke out of the body by 0.05 mm leaving the jaws in an open slot, and the end tooth land
> was below the printable floor. **Re-export before printing any gripper part.**

## 1. The one part that matters most

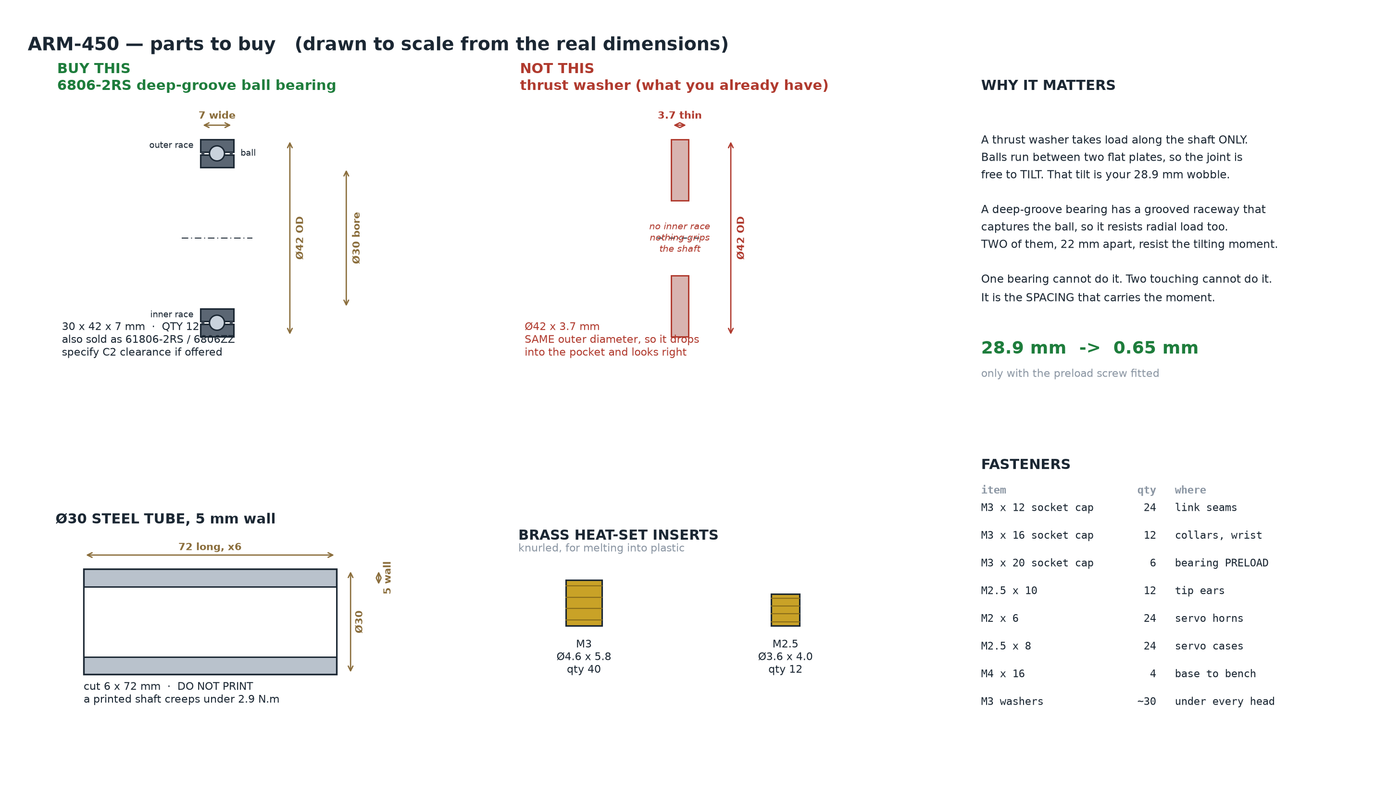
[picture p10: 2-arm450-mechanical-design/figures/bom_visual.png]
Parts to buy


### TWO bearing sizes — read this before ordering

**2026-08-21: the wrist changed to a smaller bearing.** The arm no longer uses one part
number. Ordering 12 × 6806 will leave you unable to build the wrist.

| joint | bearing | size | qty |
| --- | --- | --- | --- |
| J1 turret, J2 shoulder, J3 elbow | **6806-2RS** | 30 × 42 × 7 | **6** |
| J4 roll, J5 pitch, J6 tool roll | **6706-2RS** | 30 × 37 × 4 | **6** |

Both have the **same 30 mm bore**, so the aluminium tube, the shaft clamp and the horn
adapter are identical at every joint. Only the housing pockets differ — Ø42.00 × 7.00 at
J1–J3, Ø37.00 × 4.00 at J4–J6. The two are visibly different sizes, but **label the bags**:
a 6706 dropped into a Ø42 pocket has 2.5 mm of radial slop and will look almost right.

**Why the wrist got smaller.** The loads there are tiny. Worst case at J4, arm horizontal
with a 300 g payload: 3.3 N radial and 390 N·mm of moment, which is a 9.7 N couple across
the 40 mm bearing spacing — **safety factor 103**. A 6806 there was carrying nothing.
The swap saves **93 g**, about 6 % of the whole arm. Moment stiffness is unaffected because
it goes as bearing *spacing* squared, and the spacing is unchanged at 40 mm.

J1–J3 could take the smaller bearing too on load alone (SF 20–46), and were deliberately
left at 6806: those three set tool droop, and a thinner race in a shallower printed pocket
is exactly where a printed part loses squareness.

### 6806-2RS deep-groove ball bearing — **quantity 6** (J1, J2, J3)

| | |
| --- | --- |
| Size | **30 × 42 × 7 mm** |
| Also sold as | **61806-2RS** (ISO name), **6806ZZ** (metal shields — equally fine) |
| Seals | 2RS = rubber both sides; ZZ = metal shields |
| Clearance | ask for **C2** if offered; standard **CN** is acceptable |
| Quantity | **12** — two per joint × six joints |

**Why 12 and not 6.** A single bearing at one location cannot resist tilting. Two
bearings **22 mm apart** react the tilting couple across that span. Your link half already
has a 7 mm deep Ø42 pocket, so an assembled link takes one bearing in each half.

**This is the fix for the 28.9 mm wobble** — down to 0.65 mm, and only if the preload
screw is fitted as well. Without preload the pair buys 4×, not 44×.

### Do NOT reuse the thrust washer you already have

The `thrust ball bearing.stl` on your Desktop is a **Ø42 × 3.7 mm thrust washer**.

**It shares the same Ø42 outer diameter**, so it will drop into the new pocket and look
correct. But it is 3.7 mm thick against a 7 mm pocket, has **no inner race** for the shaft
to clamp to, and carries **zero moment**. It is the part that caused the wobble.

---

## 2. Shaft material

| item | spec | qty |
| --- | --- | --- |
| **Aluminium 6061 tube** | **Ø30 mm OD, 2 mm wall** (Ø26 bore) | ~500 mm, cut into 6 × 72 mm |
| M5 × 90 socket cap + nyloc + washers | preload through-bolt | 6 sets |
| Ø3 × 20 spring/roll pin | clamp anti-rotation | 12 |

### Why aluminium, and why not steel or printed

There are **six** joints, so six shafts. That count is what makes the material choice
decisive — a per-shaft figure that looks harmless is multiplied by six.

| shaft spec | each | × 6 | arm total | verdict |
| --- | --- | --- | --- | --- |
| Steel Ø30 × 5 | 222 g | 1332 g | 2270 g | 1070 g over budget |
| Steel Ø30 × 3 | 144 g | 863 g | 1801 g | 601 g over |
| Steel Ø30 × 2 | 99 g | 597 g | 1535 g | 335 g over |
| Alu Ø30 × 3 | 49 g | 297 g | 1235 g | 35 g over |
| **Alu Ø30 × 2** | **34 g** | **205 g** | **1144 g** | **fits, 56 g spare** |

Aluminium Ø30 × 2 is the only option that closes the 1.2 kg budget.

**Printing the shaft is not ruled out by strength.** That was the surprise when the
numbers were run: at the 2.94 N·m servo stall a printed Ø30 shaft sees 0.55 MPa of
shear (SF 32) and 0.57 MPa of bending (SF 104). Torsion and bending are nowhere near
the limit. It fails for two other reasons:

1. **The M5 preload thread strips.** Threads tapped into a printed part are cut across
   the layer lines, so they hold at roughly 18 MPa. The preload screw needs 2 N·m,
   which puts ~16 MPa in the thread — inside the scatter band. Preload is the entire
   reason the paired bearings work at all (it is what takes joint wobble from 6.55 mm
   down to 0.65 mm), so a thread that may or may not hold is not acceptable there.
2. **The press fit creeps away.** A press fit is stored elastic strain. Plastic relaxes
   under sustained strain, so the 0.02 mm interference bleeds toward zero over days and
   the inner race starts turning on the shaft.

Both failures are **local** — one thread, one bearing seat. So the fix is to put metal
only where metal is needed:

- The **tube** provides the two bearing seats and the compression path.
- A **steel M5 through-bolt** carries the preload, passing right through the Ø26 bore
  and taking a nyloc on the far side. This is better than the tapped end it replaces:
  no thread cut in soft aluminium, and the bolt is in pure tension.
- A **Ø3 roll pin** through the tube replaces the clamp's grub screws and the machined
  D-flat. It works in double shear (4241 N capacity against the 196 N the joint torque
  demands, SF 22), so nothing relies on friction and there is no flat to mill.

### One thing to check when the tube arrives

Extruded aluminium tube is held to about ±0.10–0.20 mm on OD. A bearing seat wants
roughly +0.011/+0.002. That is 10–20× looser than needed, so **measure the tube with
calipers before cutting**:

| measured OD | what to do |
| --- | --- |
| 29.98 – 30.01 | use as-is, light press |
| down to 29.92 | retaining compound (Loctite 603 or 638) — rated ~15 MPa shear across a gap up to 0.10 mm; this is the standard industrial fix for a slack seat, not a bodge |
| below 29.92 | buy drawn/ground tube, or turn it to size |

---

## 3. Fasteners

| item | qty | where it goes |
| --- | --- | --- |
| M3 heat-set inserts, Ø4.6 × 5.8 | 40 | link seams, wrist, collars |
| M2.5 heat-set inserts, Ø3.6 × 4.0 | 12 | link tip ears |
| **M3 × 20 socket cap** | 24 | link seams — see the grip note below |
| M3 × 16 socket cap | 12 | collars, wrist interfaces |
| **M5 × 90 socket cap + nyloc** | **6** | **bearing preload through-bolt — do not skip** |
| **M2.5 × 18** | 12 | tip ears — see the grip note below |
| M2.5 × 8 | 24 | servo case mounting |
| M2 × 6 | 24 | servo horns |
| M4 × 16 | 4 | base to bench |
| M3 washers | ~30 | under every head |
| M3 spacer / shim, ~2 mm | 6 | between the bearing inner races |

### Seam screw length — get this right or nothing clamps

The seam screw enters from **outside**, through the flat back face of the **tongue** half,
passes through that half, crosses the seam and threads into a brass insert set into the
**groove** half's boss. So the grip length is the full half-shell depth, not the boss height:

| | seam (M3) | tip ear (M2.5) |
| --- | --- | --- |
| grip through the tongue half | 14.50 | 14.50 |
| insert length | 5.80 | 4.00 |
| **ideal screw** | **20.30 → M3 × 20** | **18.50 → M2.5 × 18** |
| usable range | 18.0 – 22.0 | 16.9 – 19.5 |

**Too short and it never reaches the insert.** An M3 × 12 — which this list previously
specified — stops 2.5 mm short of the seam plane and does not engage anything at all.

**Too long and it bottoms in the blind hole and jacks the two halves apart**, which
recreates the seam gap the tongue-and-groove exists to close. The blind hole is 7.5 deep
against a 5.8 insert, so the ceiling is 22.0 mm for M3 and 19.5 mm for M2.5.

The heads sit **proud on the outer face** — there is no counterbore. That is deliberate:
a counterbore in a 2.4 mm wall would leave under 1 mm of material under the head.

The **M3 × 20 preload screws** are the single most important fastener in the machine.
They pull the two inner races of each pair together, removing the clearance that causes
both the wobble and the limit-cycle oscillation.

---

## 4. Actuators — you already have these

| item | qty | note |
| --- | --- | --- |
| Waveshare **ST3215** serial-bus servo | 6 | 30 kgf·cm at 12 V |

All six joints take the same servo. Confirmed against the datasheet: 45.22 × 24.72 ×
37.25 mm case, output axis **10.11 mm from one end** (not centred), horn bolt circle
**Ø14.0**, encoder 4096 counts = 0.0879°.

---

## 5. Consumables

| item | note |
| --- | --- |
| PLA+CF filament | ~600 g for the full set |
| Hardened steel nozzle, **0.6 mm** | CF is abrasive; brass wears out in a few hundred grams |
| Soldering iron with a heat-set tip | for the brass inserts, 200–220 °C |

---

## 6. Parts to PRINT — nothing here needs buying

All files are in `output/cad/`. Thirteen printed pieces, **310 g total**, about
**356 g of filament** once supports and purge are counted — so one 1 kg spool covers the
whole arm with room for a reprint.

| # | file | part name | qty | g ea | g total |
| --- | --- | --- | --- | --- | --- |
| 1 | `link_half_tongue.stl` | Link half — TONGUE side | 2 | 47.9 | 95.9 |
| 2 | `link_half_groove.stl` | Link half — GROOVE side | 2 | 44.7 | 89.5 |
| 3 | `wrist_j4_housing.stl` | J4 roll housing | 1 | 40.6 | 40.6 |
| 4 | `wrist_j5_yoke.stl` | J5 pitch yoke | 1 | 34.5 | 34.5 |
| 5 | `wrist_j6_output.stl` | J6 output / tool flange | 1 | 36.9 | 36.9 |
| 6 | `horn_adapter.stl` | Servo horn adapter | 6 | 6.6 | 39.3 |
| 7 | `shaft_clamp.stl` | Shaft clamp (split) | 2 | 6.6 | 13.3 |
| 8 | `servo_collar.stl` | Servo collar | 2 | 22.3 | 44.7 |
| 9 | `turret_j1.stl` | J1 turret | 1 | 73.5 | 73.5 |
| 10 | `base.stl` | Base pedestal | 1 | 135.5 | 135.5 |
| | | **TOTAL** | **19** | | **604** |

**19 printed pieces, 604 g.** About 694 g of filament with supports and
purge, so one 1 kg spool still covers the whole arm with room for a reprint.

> **Mass model corrected 2026-08-21.** These figures use a 0.90 fill factor, not the 0.55
> used previously. The parts are modelled **hollow** — 2.4 mm link walls, a 3.0 mm base
> shell — so the STEP volume is already the wall material, and 4 perimeters on a 0.6 nozzle
> prints a 2.4 mm wall essentially solid. The old 0.55 discounted the hollowing a second
> time and hid about 240 g.
>
> **Arm total 1437 g** = 604 printed + 360 servos + 268 bearings + 205 shafts, against
> an accepted **hard ceiling of 1450 g**. Headroom is 13 g. The pre-print gate now **fails**
> on mass rather than warning, so anything added from here is blocked rather than noted.

**`horn_adapter` is new.** It closes the torque path — servo horn to adapter to roll pin to
tube to clamp to link. Before it existed there was none: the old solid shaft carried its own
horn shoulder, and that went away when the shaft became a bought tube. It reuses the roll-pin
hole the tube already has, so the tube needs no extra machining.

Two link halves of each kind make **one** link; you need two links (upper arm and
forearm), which is where the qty 2 comes from. `fit_coupon.stl` is a test piece and is
not part of the arm.

### Orientation — decide this before any other setting

**Every bearing bore prints with its axis VERTICAL.** This is not a preference. Your
printer shrinks 0.02 mm in XY and nothing in Z, so a bore drawn by XY nozzle motion comes
out uniformly 0.02 mm under — which *is* the light press fit. Printed on its side, the
same bore shrinks in XY but not in Z and comes out **oval**, which puts back exactly the
tilt and wobble the paired-bearing redesign exists to remove.

| part | how it sits on the bed |
| --- | --- |
| Link halves | Split face flat on the bed, open side up. No supports, and the mating face prints against glass so it is genuinely flat — that flatness is what closes the seam gap you saw on the first print. Bearing bores end up vertical automatically. |
| Wrist J4 / J5 / J6 | Bearing bore axis vertical. |
| Shaft clamp | Ø30 bore vertical. |
| Servo collar | Collar axis vertical. |
| J1 turret | Bearing seat vertical. |
| Base pedestal | Foot down, upright — the natural orientation, and it puts the J1 seat vertical. |

### Slicer settings

| setting | link halves | everything else |
| --- | --- | --- |
| Material | PLA+CF | PLA+CF (PLA acceptable for collars/clamps) |
| Layer height | 0.20 mm | 0.16 mm |
| First layer | 0.25 mm | 0.25 mm |
| **Perimeters** | **4** | **6** |
| Top / bottom | 5 | 6 |
| **Infill** | **10–15 %** gyroid | **100 %** clamps & collars, 50–60 % base/turret |
| Nozzle temp | 230–245 °C | 230–245 °C |
| Bed | 60–65 °C | 60–65 °C |
| Fan | 15 % (0 % first 2 layers) | 15 % |
| Outer perimeter speed | 25 mm/s | 25 mm/s |

**Perimeters matter far more than infill here.** In bending, resistance goes as ∫y²dA, so
the outer quarter of the thickness carries 87.5 % of the moment — and that is exactly
where the perimeters live. On a 2 mm wall the walls *are* the part; raising infill from
20 % to 50 % adds core mass and buys a few percent. Going from 3 walls to 6 converts the
whole load-bearing zone from broken infill into continuous aligned extrusions.

**Dry the filament** — PLA+CF at 50 °C for 6–8 h. Moisture flashes to steam at the nozzle
and leaves voids in the weld, attacking the exact property you are printing for.

---

## 7. Print this first — the fit-test coupon

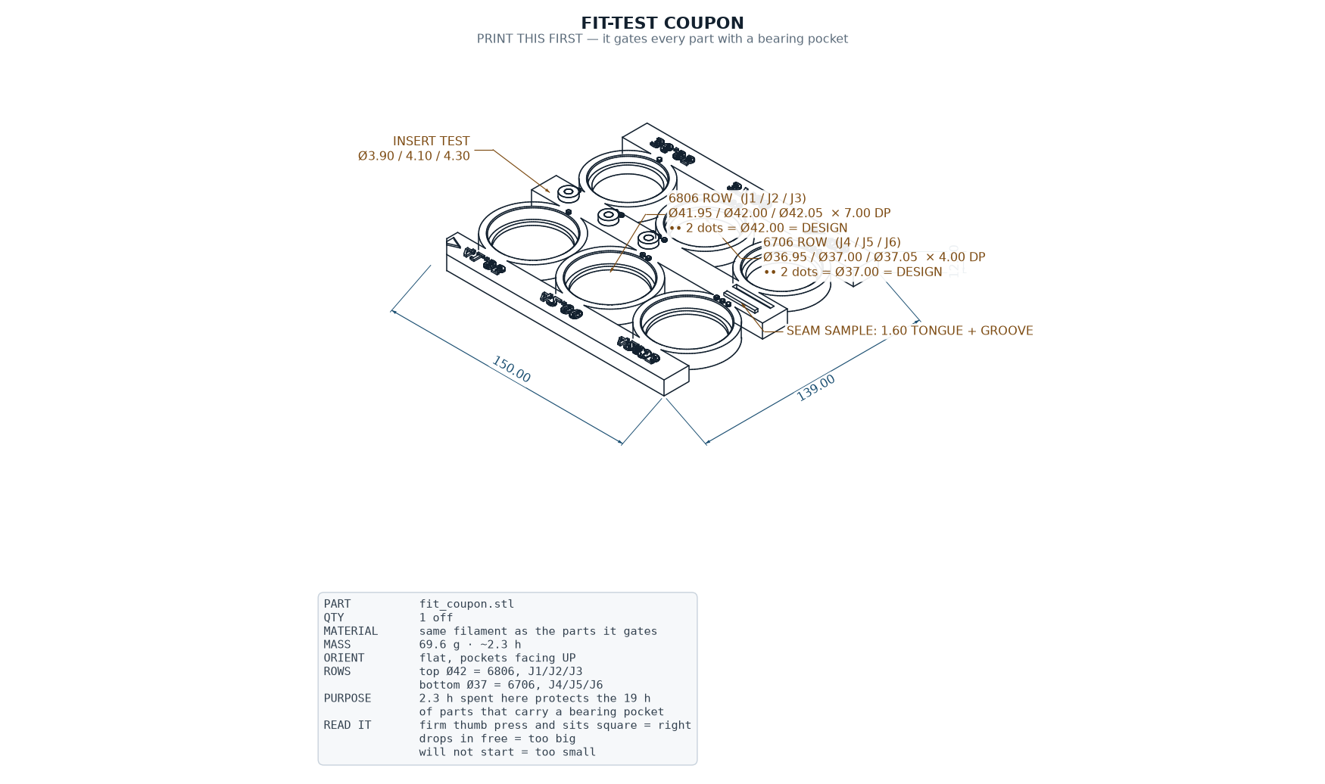
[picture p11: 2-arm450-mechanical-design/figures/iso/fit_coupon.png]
Fit coupon


`fit_coupon.stl` — **150 × 139 × 12 mm, 70 g, ≈2.3 h.**

It carries **two rows** of bearing pockets stepped 0.05 mm apart — Ø42 for the 6806 and
Ø37 for the 6706 — three insert-boss hole sizes, and a tongue-and-groove seam sample. One
print tells you which fit is right on this machine before eight hours of parts are
committed to it.

**The wrist row was added on 2026-09-01.** The wrist moved to the 6706 on 2026-08-21 and
the coupon was never followed through, so six of the arm's twelve bearings had no fit test
at all. Offered up to a Ø42 pocket a 6706 simply drops through — which reads as a faulty
bearing when the truth is that the coupon had no station for it.

**Every feature is labelled on the part itself.** Printed, three pockets 0.05 mm apart are
identical to the eye — you press a bearing in, it fits, and you have no idea which one it
was, which makes the coupon useless. So it carries:

| mark | where | reads |
| --- | --- | --- |
| raised numerals `41.95` `42.00` `42.05` | label strip along the top | 6806 pocket diameter |
| raised numerals `36.95` `37.00` `37.05` | label strip along the bottom | 6706 pocket diameter |
| raised `6806` / `6706` | right-hand end of each strip | which bearing that row is for |
| 1 / 2 / 3 raised dots | in the ring around each pocket | the same thing, upside-down-proof |
| 1 / 2 / 3 raised dots | below each insert boss | Ø3.9 / Ø4.1 / Ø4.3 |
| raised ▶ arrow | top-left of the strip | counts always ASCEND left to right |
| clipped corner | top-left | which way up the part reads |

Marks stand **0.9 mm proud and are raised, not engraved** — in dark carbon-filled PLA an
engraved character is nearly invisible, while a raised one catches the light. The numerals
are bold at 8 mm so the strokes clear two extrusion widths; anything neater would be
dropped by the slicer.

The doubling is deliberate. `05` upside down reads `50` and `95` reads `56`, and this is
the one part in the build whose entire job is to be unambiguous.

| pocket, as modelled | after your 0.02 mm shrink | expected result |
| --- | --- | --- |
| Ø41.95 | Ø41.93 | firm interference press |
| **Ø42.00** | **Ø41.98** | **light press — the design value** |
| Ø42.05 | Ø42.03 | clearance, will wobble |

**How to read it.** Press a 6806 into each pocket by hand. The right one needs firm thumb
pressure or a light tap and then sits square on the Ø38 shoulder. If it drops in freely,
that pocket is too big; if it will not start at all, too small. Whichever works, set
`BRG_FIT` in `cad/params.py` to that difference and every part regenerates.

Then test an insert at each of the three hole sizes — the boss must not split — and check
that the tongue engages the groove without rocking.

---

## 8. Print order

**~21 hours of printing on one machine.** You have three printers, so the real constraint
is not total time but *sequence* — one 2.3 h test print gates everything else.

| stage | part | qty | h ea | h stage | why here |
| --- | --- | --- | --- | --- | --- |
| **0** | `fit_coupon.stl` | 1 | 2.3 | **2.3** | **Gate. Nothing else starts until this is measured.** |
| **1** | `link_half_tongue.stl` | 2 | 1.4 | 2.8 | Longest chain of dependent parts — start the moment the gate clears |
| **1** | `link_half_groove.stl` | 2 | 1.3 | 2.5 | Prints alongside the tongue halves on a second machine |
| **2** | `wrist_j4_housing.stl` | 1 | 1.7 | 1.7 | Wrist is three parts that only mean anything together |
| **2** | `wrist_j5_yoke.stl` | 1 | 1.4 | 1.4 | |
| **2** | `wrist_j6_output.stl` | 1 | 1.5 | 1.5 | |
| **3** | `shaft_clamp.stl` | 2 | 0.3 | 0.6 | Quick; fill gaps between big jobs |
| **3** | `servo_collar.stl` | 2 | 0.9 | 1.8 | |
| **4** | `turret_j1.stl` | 1 | 3.0 | 3.0 | Large but least coupled to the bearing fit |
| **4** | `base.stl` | 1 | 5.6 | 5.6 | Longest single print, least critical — run it overnight |
| | | **13** | | **~21 h** | |

Times assume 0.6 mm nozzle, 4–6 walls, 25 mm/s outer perimeter. **Trust your slicer's
number over mine** — this is a volumetric estimate, not a simulation.

### Why this order and not simply largest-first

**Stage 0 is a hard gate.** The coupon tells you whether Ø42.00 is the right pocket. If it
is not, `BRG_FIT` changes and **every part with a bearing pocket is scrapped** — that is
stages 1, 2 and 4, roughly 19 of the 21 hours. Spending 0.9 h to protect 19 h is the whole
point. Do not start stage 1 "to save time while the coupon prints".

**Stage 1 before stage 2** because the link halves are the parts you have already printed
once and got wrong. They carry the seam, the tongue-and-groove and the bearing bosses —
the three things the first print exposed. Getting them in hand early leaves time to react.

**Base and turret last** because they are the only large parts whose fit does not feed
anything else. The base is 5.6 h and would otherwise block a machine all evening for a
part that bolts on at the very end.

### Running three machines

Put stage 1 on the two machines that can do PLA+CF and keep the third for the small
stage-3 parts. That collapses ~21 h into roughly **11 h of wall clock**. Print the base
overnight on whichever machine frees up first — it needs no supervision.

### If the bearings have not arrived

**Print anyway.** Plastic is the long-lead item; the bearings drop in afterwards. The one
thing not to do is test a joint with the old thrust washers — it will wobble and tell you
nothing about this design, because the wobble you measure will be the washer's, not the
joint's.

### After the parts come off the bed

1. Install heat-set inserts while the parts are still fresh — 200–220 °C, pressed slowly and square.
2. Check the seam closes dry, before any bearing goes in.
3. Press bearings in with the pocket **vertical**, using a flat plate — never a hammer on the inner race.
4. Assemble one joint completely and check it before building the other five.

---

## 8A. End effectors — what to buy and print

Two quick-change tools, one shared bayonet coupling. Neither is on the critical path for
the arm; print them after it.

### To buy

| item | qty | for |
| --- | --- | --- |
| **SG90 micro servo** (9 g) | 1 | drives the gripper pinion |
| **M3 × 16 thumbscrew** | 2 | the tool lock — one per tool |
| M3 × 8 socket cap | 4 | SG90 mounting, dock target bolt-down |

The SG90 is the only new actuator in the whole design. The **docking tool needs none** —
its latch is a bayonet and **J6 turns it**.

### To print — 7 parts

| order | file | qty | g | note |
| --- | --- | --- | --- | --- |
| 1 | `tool_adapter.stl` | 1 | 14.4 | bolts to J6 once and stays |
| 2 | `tool_dock.stl` | 1 | 48.0 | docking probe |
| 2 | `dock_target.stl` | 1 | 12.6 | passive port, bench test — not on the arm |
| 2 | `dock_target_sealed.stl` | 1 | 12.5 | the same port with an O-ring groove, for FLUID transfer |
| 3 | `tool_gripper.stl` | 1 | 43.4 | gripper body, SG90 pocket |
| 3 | `gripper_jaw.stl` | 2 | 5.7 | **100 % infill**, print the second mirrored |
| 3 | `gripper_pinion.stl` | 1 | 2.3 | **100 % infill — small teeth** |

Same PLA+CF spool as the arm. **Print the pinion and the jaw racks at 100 % infill**:
the teeth are 2 mm and sparse infill leaves them hollow.

Dock first if you want the earliest useful test — `dock_target` lets the docking interface
be proved on a bench with no arm, no fuel and no flight software.

> **Both docking parts were re-cut on 2026-08-22 and the earlier STLs are dead.** The probe
> exported as four solids (the three latch lugs floated clear of the bore), the target's
> capture groove had severed its own spigot tip, and the cone was deeper than the spigot
> was long so the two could not have mated at any depth or angle. Throat is now Ø16, mouth
> Ø34, cone 9 mm deep, spigot 21 mm. The mate is simulated mesh-on-mesh in
> `check_tool_fit.py` — insert, latch, catch, release — see ARM450_END_EFFECTORS.pdf.

### Mass — a tool is payload, not arm

The arm is 1365 g against its 1450 g hard ceiling with 85 g spare, and neither tool fits in
that. Neither needs to: every load analysis assumed **300 g at the TCP**. The heaviest
configuration — adapter + gripper + SG90 — is **75 g**, a quarter of the allowance.
Only one tool is fitted at a time.

### One consequence worth knowing — settled

**A fitted tool extends the arm past its 450 mm specification.** The 450 mm is the arm,
base to the J6 tool face; the tool is payload hanging off the end of it.

| fitted | reach past J6 | max reach | horizontal reach |
| --- | --- | --- | --- |
| bare J6 face | — | 450 mm | 360 mm |
| pen | 30 mm | 480 mm | 390 mm |
| **gripper** | **42 mm** | **492 mm** | **402 mm** |
| dock probe | 36 mm | 486 mm | 396 mm |

**Settled 2026-08-22: 492 mm with a gripper is acceptable.** 450 mm binds the arm, not the
system. Recorded as `params.SYSTEM_REACH_MAX = 495 mm` and checked in preflight stage 8, so
that a *later, longer* tool cannot quietly push the system past what was agreed — if one
needs more, that is a decision to re-make rather than a number to edit.

The "reach past J6" column is measured off the assembly, not typed in. The dock figure was
43 mm until the capture cone was shortened on 2026-08-22; it is 36 mm now.

---

## 9. Where to buy — links

Checked 2026-08-20. **My web search only returns US retailers**, so the links below are
US-based. If you are ordering in India, the two right-hand columns give the exact search
term and the local stores that carry this class of part — use those instead. Product links
rot; the **spec** is the thing to match, not the link.

### Bearings — 6806-2RS × 6  ·  6706-2RS × 6

| supplier | note |
| --- | --- |
| [Bearings Direct — 6806-2RS 30×42×7](https://bearingsdirect.com/6806-2rs-ball-bearing-30x42x7-sealed/) | ~$14.74 each, 24 h dispatch. Six needed, for J1–J3. |
| [Amazon — 10 pcs 6806-2RS](https://www.amazon.com/Bearing-6806-2RS-61806-2RS1-30x42x7-Bearings/dp/B0CHJ53SCS) | 10-pack, cheapest per unit; order 2 packs. |
| [VXB — 6806-2RS premium sealed](https://vxb.com/products/6806-2rs-bearing-30x42x7-sealed) | Same-day dispatch. |
| [USA Roller Chain — 6806-2RS](https://usarollerchain.com/products/2278-brg-6806-2rs) | ABEC-3, tighter grade than the Amazon generics. |
| [The Big Bearing Store](https://thebigbearingstore.com/6806-2rs-6806-zz-radial-ball-bearing-30x42x7/) | Bulk pricing. |
| [123Bearing (EU)](https://www.123bearing.com/bearing-housing/deep-groove-bearing/single-row/6806-2rs) | European option. |

**For the 6706 (30 × 37 × 4), qty 6** — a thin-section deep-groove bearing. Less commonly
stocked than the 6806, so order early. Search **`6706 2RS 30x37x4`**, also sold as
**61706-2RS**. If it proves hard to source locally, the fallback is to run 6806 throughout
and accept 1458 g instead of 1365 g — the design works either way, it is only mass.

**India:** [Robu.in bearings category](https://robu.in/product-category/mechanical-parts-and-tools/bearings/) ·
[Robokits India](https://robokits.co.in/). Search term: **`6806 2RS bearing 30x42x7`**
(also sold as **61806-2RS**). If neither stocks it, any local bearing dealer will — this is
a standard bicycle bottom-bracket size and is stocked everywhere.

**When ordering, get 2RS (rubber sealed), not ZZ (metal shielded).** 2RS holds grease
better in a joint that mostly sits still and moves slowly.

### Aluminium tube — Ø30 OD × 2 mm wall, ~500 mm

| supplier | note |
| --- | --- |
| [Online Metals — 30 mm OD × 2 mm wall × 26 mm ID round tube](https://www.onlinemetals.com/en/buy/aluminum/30mm-od-x-2mm-wall-x-26mm-id-aluminum-round-tube-6060-metric-60-length/pid/22433) | **Exact match.** Alloy is 6060 rather than 6061 — slightly softer, and completely fine here: our safety factors are 21–31, so the alloy difference is irrelevant. Sold in 60″ lengths; you need 500 mm. |
| [Chalco Aluminum](https://www.chalcoaluminum.com/product/aluminum-tube/6061-aluminum-tube/) | True 6061, OD 3–600 mm, wall from 0.5 mm, min order 1 piece on stock sizes. |
| [Online Metals — 6061 pipe range](https://www.onlinemetals.com/en/buy/aluminum-pipe-6061) | Browse if the metric size is out of stock. |

**India:** any local aluminium/hardware market stocks this. Search term:
**`aluminium round tube 30mm OD 2mm wall 6061`** or **`26mm ID`**. Ask for **round tube**,
not pipe — pipe is sized by nominal bore and you will get the wrong OD.

**Measure the OD with calipers before you cut it.** See section 2 — extrusion tolerance is
10–20× looser than a bearing seat needs, and this one check decides whether you use it
as-is, add retaining compound, or send it back.

### Heat-set inserts — M3 × 40, M2.5 × 12

| supplier | note |
| --- | --- |
| [Amazon — 140 pcs M3, 5.7 long × 4.6 OD](https://www.amazon.com/Threaded-Inserts-knurled-Printing-Components/dp/B0DDWS7BTS) | **Matches our Ø4.6 × 5.8 spec.** One pack covers the arm several times. |
| [Prusa — M3 inserts, 100 pcs](https://www.prusa3d.com/product/threaded-inserts/) | Consistent quality, well known dimensions. |
| [MakerTechStore — M3 heat-set](https://www.makertechstore.com/products/heat-set-threaded-inserts-m3-threads) | |
| [AndyMark — M3 heat-set](https://andymark.com/products/m3-heat-set-threaded-insert) | |

**India:** Robu.in and Robokits both stock these. Search term:
**`M3 heat set insert brass knurled 4.6mm`**.

The critical dimension is **OD 4.6 mm**, because that is what our Ø4.1 boss hole is sized
for. A 5.0 mm OD insert will split the boss. The fit coupon carries Ø3.9 / 4.1 / 4.3 test
holes so you can confirm before committing.

### Fasteners, roll pins, retaining compound

Standard stock — any fastener supplier, or Amazon/Robu/Robokits. Nothing here is special:

- M5 × 90 socket cap + M5 nyloc + M5 washers, 6 sets — **the preload bolts, do not skip**
- M3 × 12 / × 16 socket cap, M2.5 × 8
- Ø3 × 20 spring (roll) pins, qty 12
- **Loctite 603 or 638** retaining compound — only if the tube measures loose

### What you already have

Six ST3215 servos, and the 3 kg-cm-class hardware from the earlier build. Nothing to
order there.

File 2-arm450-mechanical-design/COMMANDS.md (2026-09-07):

# ARM-450 — Command Reference

Every alias, every raw ROS 2 equivalent, and the commands worth knowing when
something looks wrong.

**This page is generated.** The alias table below is parsed out of
`arm450_aliases.sh` by `make_commands.py`; the trajectory options are read from
`plan_sine.py --help`. Nothing here is typed by hand, because a hand-written
command sheet is precisely the document that goes stale without anyone noticing.

---

## 1. Install, once

```bash
echo 'source ~/ros2_ws/arm450_design/arm450_aliases.sh' >> ~/.bashrc
exec bash
a450help          # the whole list, any time
```

If the workspace has never been built on this machine:

```bash
cd ~/ros2_ws
colcon build --packages-select arm450_description arm450_sine --symlink-install
source install/setup.bash
```

---

## 2. The short version

```bash
a450src           # source ROS 2 Jazzy + this workspace
a450run           # arm + gripper + sine trace in RViz
a450slow          # slow it down to watch the wrist
a450stop          # stop everything
```

**Use a plain Ubuntu terminal.** Inside the VS Code integrated terminal the snap
sets `GTK_PATH`, RViz loads a GTK module from the snap tree, that module drags in
the snap's glibc, and `rviz2` dies on startup with

```
libpthread.so.0: undefined symbol: __libc_pthread_init, version GLIBC_PRIVATE
```

`a450unsnap` (`unset GTK_PATH`) fixes it. Outside the editor the variable is not
set and the problem does not exist.

---

## 3. Every alias

Parsed from `arm450_aliases.sh`, so this table cannot drift from what your shell actually does.

### environment

| command | runs |
| --- | --- |
| `a450src` | `source /opt/ros/jazzy/setup.bash && source $ARM450_WS/install/setup.bash && echo "ARM-450 env ready (ROS 2 jazzy)"` |
| `a450build` | `cd $ARM450_WS && source /opt/ros/jazzy/setup.bash && colcon build --packages-select arm450_description arm450_sine && source $ARM450_WS/install/set…` |
| `a450cd` | `cd $ARM450_DIR` |

### run / stop

| command | runs |
| --- | --- |
| `a450run` | `ros2 launch arm450_sine sine.launch.py` |
| `a450jog` | `ros2 launch arm450_description display.launch.py` |
| `a450stop` | `pkill -f sine_node; pkill -f robot_state_publisher; pkill -f rviz2; echo "ARM-450 nodes stopped"` |

### speed (live, while it is running)

| command | runs |
| --- | --- |
| `a450speed()` | `a450speed 60 -> 60 Hz` |
| `a450slow` | `ros2 param set /arm450_sine rate 8.0` |
| `a450normal` | `ros2 param set /arm450_sine rate 25.0` |
| `a450fast` | `ros2 param set /arm450_sine rate 75.0` |
| `a450rate` | `ros2 param get /arm450_sine rate` |

### shape (needs a re-solve, then relaunch)

| command | runs |
| --- | --- |
| `a450plan()` | `a450plan --amplitude 0.04 --cycles 4 --points 300` |
| `a450cycles4` | `a450plan --cycles 4 --points 300` |
| `a450cycles6` | `a450plan --cycles 6 --points 400` |
| `a450reset` | `a450plan --amplitude 0.04 --cycles 2 --span 0.14 --board-x 0.30 --z-center 0.22 --points 240` |
| `a450tipik` | `a450plan --board-x 0.30 --z-center 0.26 --w-ori 0.2 --tip-ik` |

### inspect

| command | runs |
| --- | --- |
| `a450joints` | `ros2 topic echo /joint_states --once` |
| `a450hz` | `ros2 topic hz /joint_states` |
| `a450tcp` | `ros2 run tf2_ros tf2_echo base_link tcp` |
| `a450tip` | `ros2 run tf2_ros tf2_echo base_link tool_tip` |
| `a450nodes` | `ros2 node list` |
| `a450params` | `ros2 param list /arm450_sine` |

### design / docs

| command | runs |
| --- | --- |
| `a450urdf()` | `a450urdf [tool]  — regenerate BOTH urdfs and install them` |
| `a450tool()` | `a450tool gripper / dock / none` |
| `a450wrist` | `rviz2 -d $ARM450_WS/install/arm450_description/share/arm450_description/rviz/arm450_tool.rviz` |
| `a450unsnap()` | `unset GTK_PATH — lets rviz2 start in a VS Code snap terminal` |
| `a450gate` | `( cd $ARM450_DIR && python3 preprint_check.py )` |
| `a450flight` | `( cd $ARM450_DIR && python3 preflight.py )` |
| `a450cad` | `( cd $ARM450_DIR/cad && for f in *.py; do [ "$f" = params.py ] && continue; python3 "$f"; done )` |
| `a450docs` | `ls -lh $ARM450_DIR/output/*.pdf` |
| `a450cmds` | `( cd $ARM450_DIR && python3 make_commands.py && python3 build_pdf.py COMMANDS.md )` |
| `a450open` | `xdg-open $ARM450_DIR/output` |

### Notes carried in the file

**`a450plan()`** — --tool matters. The trajectory drives the J6 FLANGE; the fitted tool's working point is further out (gripper 42 mm), so the board the TIP traces is 42 mm beyond --board-x. Passing --tool also moves the RViz path marker onto the tip, which is why the yellow curve used to float behind the fingers. ARM450_TOOL follows whatever a450tool last fitted.

**`a450cycles4`** — a450cycles2 removed 2026-08-22: it was --cycles 2 --points 240, which is the shipped default, so it did exactly what a450reset does. Two names for one thing is how they drift apart.

**`a450reset`** — z-center is 0.22, NOT 0.20. At 0.20 the exact-mesh check found the upper arm grazing the base pedestal on 30 % of waypoints. This alias still said 0.20 long after plan_sine.py was fixed, so `a450reset` would have quietly written a COLLIDING trajectory over the good one.

**`a450tipik`** — board fixed and cannot move? drive the TIP onto --board-x instead of the flange. Harder solve -- the flange ends up 42 mm nearer the base, on a poorer IK branch -- so it wants a higher trace and a stronger orientation weight.

**`a450tcp`** — tcp is the J6 FLANGE, not the working point. With a tool fitted that is the frame that hid the 42 mm gap, so it is labelled and a450tip is the one to use.

**`a450urdf()`** — Rebuilds BOTH urdfs. It used to rebuild only arm450.urdf (the box-primitive one); the mesh urdf RViz actually loads was left stale, which is how RViz came to be showing a model that did not match the design.

**`a450tool()`** — swap the fitted end effector and rebuild in one go

**`a450wrist`** — camera parked on the wrist, so the tool is actually visible

**`a450unsnap()`** — rviz2 dies instantly in a VS Code snap terminal with libpthread.so.0: undefined symbol: __libc_pthread_init, GLIBC_PRIVATE The cause is GTK_PATH, which the snap points at its own GTK module directory. rviz2's Qt/GTK integration loads a module from there and that module drags in the snap's core20 glibc alongside the system one. Nothing else matters -- LD_LIBRARY_PATH, PATH and LOCPATH are all red herrings; unsetting this one variable is the whole fix.

**`a450cmds`** — regenerate the command reference. It is PARSED from this file and from plan_sine.py --help, so editing an alias and re-running this keeps the PDF honest -- which is the whole reason it is generated rather than typed.

---

## 4. Environment variables

| variable | value |
| --- | --- |
| `ARM450_WS` | `~/ros2_ws` |
| `ARM450_DIR` | `~/ros2_ws/arm450_design` |
| `ARM450_TRAJ` | `~/ros2_ws/src/arm450_sine/sine_traj.npz` |
| `ARM450_TOOL` | `gripper` |

`ARM450_TOOL` follows whatever `a450tool` last fitted, and `a450plan` passes it to `plan_sine.py` automatically.

---

## 5. Raw ROS 2 — the same things without aliases

Useful when you are on another machine, or debugging and want to see exactly
what is being run.

### Launch

```bash
source /opt/ros/jazzy/setup.bash
source ~/ros2_ws/install/setup.bash

ros2 launch arm450_sine sine.launch.py                 # trace, with RViz
ros2 launch arm450_sine sine.launch.py traj_file:=/path/to/other.npz
ros2 launch arm450_description display.launch.py       # RViz + joint sliders
ros2 launch arm450_description display.launch.py gui:=false
```

### Run a single node

```bash
ros2 run arm450_sine sine_node --ros-args \
    -p traj_file:=$HOME/ros2_ws/src/arm450_sine/sine_traj.npz \
    -p approach_time:=3.0 \
    -p loop_mode:=pingpong

URDF=~/ros2_ws/install/arm450_description/share/arm450_description/urdf
ros2 run robot_state_publisher robot_state_publisher --ros-args \
    -p robot_description:="$(cat $URDF/arm450_meshes.urdf)"

RVIZ=~/ros2_ws/install/arm450_description/share/arm450_description/rviz
rviz2 -d $RVIZ/arm450.rviz
```

Three RViz configs ship: `arm450.rviz` (whole arm), `arm450_tool.rviz` (camera on
the wrist), `arm450_side.rviz` (looks along −Y, so board distance and tip are
unambiguous — perspective in the orbit views makes the traced curve look like it
passes through the gripper when it does not).

### Parameters, live

```bash
ros2 param list /arm450_sine
ros2 param get  /arm450_sine rate
ros2 param set  /arm450_sine rate 60.0      # 0.5 – 500 Hz, takes effect at once
ros2 param dump /arm450_sine
```

`rate` is the only parameter that can be changed while running and have an
effect. `create_timer()` fixes its period at construction, so the node rebuilds
the timer in a parameter callback — without that, `ros2 param set` would be
accepted and then silently ignored.

### Topics

```bash
ros2 topic list
ros2 topic echo /joint_states --once
ros2 topic hz   /joint_states                # should sit at the `rate` param
ros2 topic info /arm450/trajectory --verbose
ros2 topic echo /arm450/trajectory --once    # the whole solved path, latched
ros2 topic echo /sine_path --once            # the marker RViz draws
```

`/joint_states` is a **visualisation** stream — a real controller will not follow
it. `/arm450/trajectory` is the same path as a `JointTrajectory` with timestamps
and velocities, published once and latched (`TRANSIENT_LOCAL`), which is what a
`FollowJointTrajectory` action wants.

### Frames

```bash
ros2 run tf2_ros tf2_echo base_link tool_tip     # where the tool actually works
ros2 run tf2_ros tf2_echo base_link tcp          # the J6 flange, 42 mm behind it
ros2 run tf2_tools view_frames                   # writes frames.pdf
ros2 topic echo /tf_static --once
```

**`tcp` is not the working point.** It is the J6 tool face; a fitted gripper
works 42 mm further out at `tool_tip`. Reading `tcp` and assuming it was the pen
is what put the traced curve 42 mm behind the fingers.

### Recording and replay

```bash
ros2 bag record /joint_states /sine_path /tf /tf_static -o arm450_trace
ros2 bag info arm450_trace
ros2 bag play arm450_trace --loop
```

### Inspecting the model

```bash
check_urdf $URDF/arm450_meshes.urdf
urdf_to_graphiz $URDF/arm450_meshes.urdf     # writes arm450.gv / .pdf
ros2 node list
ros2 node info /arm450_sine
ros2 doctor --report
```

---

## 6. Re-solving the trajectory

The ROS node **replays** a solved file; it does not do IK. Changing amplitude,
cycles, span or board distance needs `plan_sine.py`, then a relaunch.

```

usage: plan_sine.py [-h] [--amplitude AMPLITUDE] [--cycles CYCLES]
                    [--span SPAN] [--board-x BOARD_X] [--points POINTS]
                    [--z-center Z_CENTER] [--tool {dock,gripper,none,pen}]
                    [--tip-ik] [--w-ori W_ORI] [--out OUT]

Re-solve the ARM-450 sine trajectory. Changing amplitude or cycles REQUIRES
this step -- the ROS node only replays a solved file, it does not do IK.

options:
  -h, --help            show this help message and exit
  --amplitude AMPLITUDE
                        sine amplitude in m (default 0.04)
  --cycles CYCLES       number of full sine cycles (default 2.0)
  --span SPAN           trace length along the board in m (default 0.14)
  --board-x BOARD_X     board distance from base in m (default 0.3)
  --points POINTS       waypoints (default 240); more = smoother, slower solve
  --z-center Z_CENTER   trace centre height in m (default 0.22). THE lever for
                        large amplitude: at 0.20 the shoulder J2 sits on its
                        +115 deg stop, so amplitude past 40 mm degrades. 0.17
                        frees it -- 80 mm amplitude solves to 0.39 mm rms
                        there vs 1.99 mm at 0.20.
  --tool {dock,gripper,none,pen}
                        fitted end effector. Its working point is past the J6
                        flange (gripper 42 mm, dock 36, pen 30), so the board
                        the TIP traces is that much further out than --board-x
                        unless you also pass --tip-ik.
  --tip-ik              drive the TOOL TIP onto --board-x instead of the
                        flange. Use when the board cannot move. Harder solve
                        -- try --z-center 0.26 --w-ori 0.2 with a gripper.
  --w-ori W_ORI         orientation weight (default 0.05). Raise it with
                        --tip-ik: a tilt moves the tip, so at 0.05 the solver
                        trades 21 deg of tilt for position error.
  --out OUT
```

### The board distance changes with a tool fitted

The trajectory drives the **J6 flange**. A fitted tool works further out, so the
board the tip traces is that much beyond `--board-x`:

| fitted | works past the flange | board goes at |
| --- | --- | --- |
| none | — | 300 mm |
| pen | 30 mm | 330 mm |
| **gripper** | **42 mm** | **342 mm** |
| dock probe | 36 mm | 336 mm |

`plan_sine.py` prints the number so you never work it out:

```
  TOOL: gripper, working point 42 mm past the J6 flange
  IK drives the FLANGE
  *** PUT THE BOARD AT x = 342 mm ***  (flange sweeps x = 300 mm)
```

If the board cannot move, `a450tipik` drives the tip onto 300 mm instead. It is
the worse option — 2.87° joint steps against 2.09°, and 0.087 mm rms against
0.055 — because the flange ends up 42 mm nearer the base on a poorer IK branch.
It also needs `--z-center 0.26` and `--w-ori 0.2`: with a tool fitted a tilt
moves the tip, so at the flange-tuned weight the solver trades **21° of tool
tilt** for position error.

**Keep amplitude at 0.04.** Past 40 mm the shoulder J2 reaches its +115° stop and
path error goes 0.19 → 1.35 mm. Cycles are free — raise `--points` to about
60 × cycles and the error does not move.

---

## 7. Design-side commands

```bash
cd ~/ros2_ws/arm450_design

python3 preflight.py            # the full 8-stage pre-print check  (a450flight)
python3 preprint_check.py       # the fast parts gate               (a450gate)
python3 check_tool_fit.py       # end-effector interfaces + the docking mate
python3 check_sine_clear.py     # sine path vs exact mesh, per fitted tool
python3 workspace.py            # reach and swept volume, per fitted tool
python3 interference.py         # joint-limit collision sweep

python3 cad/end_effector.py     # rebuild the six tool parts
python3 cad/volumes.py          # refresh the exact STEP volumes
python3 draw_iso.py             # isometric sheets   -> figures/iso/
python3 draw_3view.py           # third-angle sheets -> figures/3view/
python3 build_pdf.py REPORT.md  # any .md -> output/ARM450_*.pdf
```

### Swapping the fitted end effector

```bash
a450tool gripper     # or: dock | none
```

That regenerates both URDFs, copies the meshes, colcon-builds, and re-solves the
trajectory so the path marker lands on the new tool's tip. Then `a450run`.

Manually:

```bash
cd ~/ros2_ws/arm450_design
EMIT=1 TOOL=dock python3 generate_urdf_meshes.py
cp meshes/*.stl ~/ros2_ws/src/arm450_description/meshes/
cp arm450_meshes.urdf ~/ros2_ws/src/arm450_description/urdf/
cd ~/ros2_ws && colcon build --packages-select arm450_description --symlink-install
```

---

## 8. When something looks wrong

| symptom | cause | fix |
| --- | --- | --- |
| `rviz2` exits instantly, GLIBC symbol error | VS Code snap sets `GTK_PATH` | `a450unsnap`, or use a plain terminal |
| RViz shows blocks, not the real arm | loaded `arm450.urdf` (primitives) instead of `arm450_meshes.urdf` | use the launch file, or `a450urdf` |
| meshes missing, arm is invisible | `package://` name wrong — it is `arm450_description`, never `arm450_design` | rebuild with `a450urdf` |
| no motion in RViz | `sine_node` not running, or Fixed Frame is not `world` | `a450nodes`, check the RViz Global Options |
| arm jumps back to the start each pass | `loop_mode:=wrap` | leave it at `pingpong` |
| traced curve sits behind the gripper | path marker on the flange | re-solve with `--tool`, see §6 |
| `a450stop` kills your terminal | you used `pkill -f ros2` | `a450stop` names each executable for this reason |

### Stopping things safely

```bash
a450stop        # pkill -f sine_node; pkill -f robot_state_publisher; pkill -f rviz2
```

Never `pkill -f ros2`. The pattern matches your own shell's command line and
kills the terminal you are typing in. For the same reason, a wait loop built on
`pgrep -f <script>` never exits — it matches itself.

---

## 9. Reference PDFs

| file | what is in it |
| --- | --- |
| `ARM450_RUN.pdf` | running the simulation, in full |
| `ARM450_URDF.pdf` | the kinematic chain, every link and joint |
| `ARM450_BUY.pdf` | what to buy, what to print, print order |
| `ARM450_PREFLIGHT.pdf` | the 8-stage pre-print gate |
| `ARM450_END_EFFECTORS.pdf` | the gripper and the docking probe |
| `ARM450_WORKSPACE.pdf` | reach and swept volume |
| `ARM450_DRAWINGS_ISO.pdf` | dimensioned isometric sheets, 18 parts |
| `ARM450_DRAWINGS_3VIEW.pdf` | third-angle sheets, 18 parts |
| `ARM450_LOG.pdf` | what changed, when, and why |
| `ARM450_LESSONS.pdf` | the mistakes, and the rules they produced |

`a450docs` lists them; `a450open` opens the folder.

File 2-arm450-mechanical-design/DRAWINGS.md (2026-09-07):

# ARM-450 — Parts, Drawings and Dimensions

- **Source:** `~/Desktop/Robotic_arm_design/` (Fusion 360 export)
- **Date:** 2026-08-13
- **Units:** all dimensions in millimetres
- **Method:** every dimension below was measured directly from the STL geometry, not read off a drawing. Envelope = axis-aligned bounding box of the part as exported.

---

## 1. How to read this document

Each part carries a part number, its measured envelope, an estimated printed mass, and a status. Status meanings:

- **keep** — Carry forward unchanged.
- **revise** — Minor revision — fillets and bearing seats.
- **LENGTHEN** — Lengthen to 145 mm joint-to-joint.
- **MISMATCH** — Envelope does not pair with its base shell — check before reuse.
- **REJECT** — Unequal link length; creates a dead zone and exceeds 450 mm.
- **REDESIGN** — Redesign as a full-perimeter collar; current form is understrength.
- **FAILS** — Fails at servo stall torque. Do not reprint as-is.
- **COTS** — Commercial off-the-shelf, not printed.
- **REPLACE** — Replace with a spaced, preloaded pair of deep-groove bearings.

**Important:** the envelope is not the same as the kinematic link length. A capsule link has a circular boss at each end and the joint axis sits at the boss centre, inset from the part end by the boss radius. Section 4 gives the true joint-to-joint lengths.

---

## 2. Assembly overview

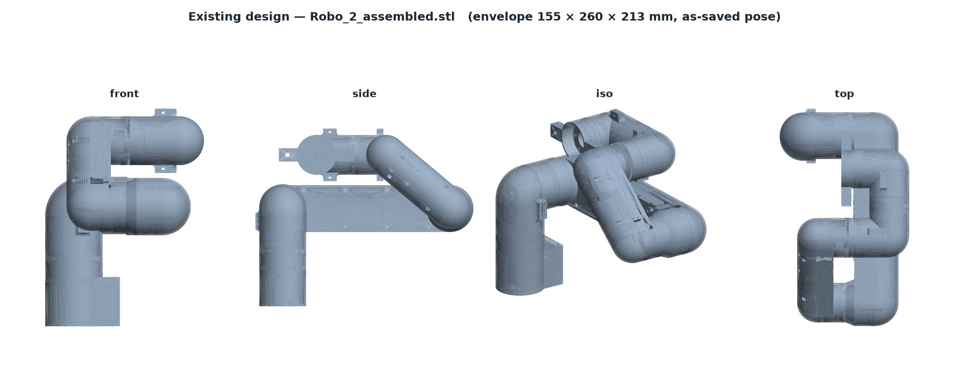
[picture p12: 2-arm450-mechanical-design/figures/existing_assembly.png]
Assembly


The as-printed assembly measures 155 × 260 × 213 mm in the pose it was saved in. Fully extended the chain is longer; section 4 gives the dimension chain that must total 450 mm.

---

## 3. Master parts list

| Part | File | Group | Function | Envelope (mm) | Wall | Mass est. | Status |
| --- | --- | --- | --- | --- | --- | --- | --- |
| A-01 | base_p1 | Base | Lower base shell, D-profile | 72.9 × 56.0 × 43.0 | 2.7 | 17.3 g | keep |
| A-02 | base_p2 | Base | Base cover / floor plate | 72.9 × 56.0 × 18.0 | 2.8 | 8.8 g | keep |
| A-03 | Motor_mount_base | Base | J1 servo mount, top-hat flange | 46.0 × 46.0 × 33.0 | 2.3 | 4.9 g | revise |
| B-01 | link1_base | Link | Upper-arm shell, lower half | 147.5 × 47.5 × 29.0 | 2.0 | 15.8 g | LENGTHEN |
| B-02 | link1_cover | Link | Upper-arm shell, upper half | 196.5 × 46.5 × 33.2 | 2.2 | 22.1 g | MISMATCH |
| B-03 | link2_base | Link | Forearm shell, lower half | 147.5 × 47.5 × 29.0 | 2.0 | 15.8 g | LENGTHEN |
| B-04 | link2_cover | Link | Forearm shell, upper half | 146.5 × 46.5 × 33.2 | 1.9 | 14.8 g | LENGTHEN |
| B-05 | link1_base_1.1 | Link | Upper-arm shell rev 1.1 (longer) | 256.0 × 56.0 × 34.5 | 2.7 | 43.2 g | REJECT |
| B-06 | link1_cover1.1 | Link | Upper-arm cover rev 1.1 | 256.0 × 56.0 × 33.0 | 2.1 | 30.9 g | REJECT |
| B-07 | link2_cover2.1 | Link | Forearm cover rev 2.1 | 147.5 × 47.5 × 35.8 | 1.9 | 17.5 g | keep |
| C-01 | J2_p1 | Joint | J2 shoulder yoke, driven side | 80.0 × 64.8 × 85.5 | — | — | revise |
| C-02 | J2_p2 | Joint | J2 shoulder yoke, idler side | 40.0 × 64.8 × 66.0 | 2.0 | 8.3 g | revise |
| C-03 | J4_p1 | Joint | J4 yoke, driven side | 63.8 × 57.0 × 79.8 | — | — | revise |
| C-04 | J4_p2 | Joint | J4 yoke, idler side | 35.7 × 57.0 × 61.7 | 2.2 | 7.7 g | revise |
| C-05 | Motor_housing_new | Joint | Elbow motor housing | 55.5 × 53.0 × 69.0 | 2.6 | 17.4 g | keep |
| D-01 | wrist_p1 | Wrist | Wrist body, driven side | 58.2 × 62.7 × 72.2 | 2.5 | 12.5 g | keep |
| D-02 | wrist_p2 | Wrist | Wrist body, idler side | 31.7 × 62.7 × 58.2 | 2.2 | 7.0 g | keep |
| E-01 | Motor_mount_J1 | Mount | J1 servo mount | 40.0 × 40.0 × 24.0 | 2.1 | 3.1 g | REDESIGN |
| E-02 | Motor_mount_J2 | Mount | J2 servo mount | 46.0 × 46.0 × 38.2 | 2.3 | 5.4 g | REDESIGN |
| E-03 | Motor_mount_wrist | Mount | Wrist servo mount | 40.0 × 40.0 × 23.0 | 2.1 | 3.0 g | REDESIGN |
| E-04 | Motor_mount | Mount | Generic servo mount | 40.0 × 40.0 × 28.0 | 2.2 | 3.6 g | REDESIGN |
| E-05 | Motor_mount_changed_ 2mm_length | Mount | Servo mount, +2 mm variant | 40.0 × 40.0 × 30.0 | 2.4 | 4.1 g | REDESIGN |
| F-01 | Motor_fixer_j2_p1 | Fixer | J2 servo clamp, 6 mm plate | 6.0 × 41.0 × 36.0 | 1.7 | 0.9 g | FAILS |
| F-02 | Motor_fixer_j2_p2 | Fixer | J2 servo clamp, 4 mm plate | 4.0 × 50.0 × 36.0 | 1.4 | 0.6 g | FAILS |
| F-03 | motor fixer | Fixer | Servo clamp, U-channel | 64.8 × 27.2 × 31.0 | 2.2 | 4.5 g | FAILS |
| F-04 | motor fixer_wrist | Fixer | Wrist servo clamp | 57.0 × 27.2 × 31.0 | 2.1 | 4.2 g | FAILS |
| G-01 | ST3215 | COTS | Feetech ST3215 serial-bus servo | 45.2 × 37.8 × 24.7 | 4.3 | 23.4 g | COTS |
| G-02 | thrust ball bearing | COTS | Thrust ball bearing Ø42 | 42.0 × 3.7 × 42.0 | — | — | REPLACE |
| G-03 | pin | Tool | Grasp pin / end effector | 47.5 × 90.0 × 23.0 | 2.9 | 9.9 g | keep |

Mass estimates assume PLA at roughly 35 % infill (0.55 g/cm³ effective) and are indicative only — weigh the real parts to confirm. Wall is the effective shell thickness computed as 2V/A; it is meaningless for solid parts and is shown as a dash where the mesh is not watertight.

---

## 4. Kinematic dimension chain — the 450 mm budget

| Segment | Length | Notes |
| --- | --- | --- |
| Round base height | 50 | user's sketch dimension |
| Base top → J2 shoulder axis | 40 | shoulder barrel centre |
| **L2 upper arm, J2 → J3** | **145** | must equal L3 |
| **L3 forearm, J3 → J5** | **145** | must equal L2 |
| Wrist centre → TCP | 70 | J6 flange plus tool |
| **TOTAL** | **450** | meets the requirement exactly |

Horizontal reach from the J1 axis is 145 + 145 + 70 = **360 mm**.

### Why L2 must equal L3

The reachable region of a two-link chain is an annulus whose **inner radius is |L2 − L3|**. Equal links collapse that inner hole to zero. Unequal links punch a dead zone directly in front of the robot that no amount of joint travel can reach.

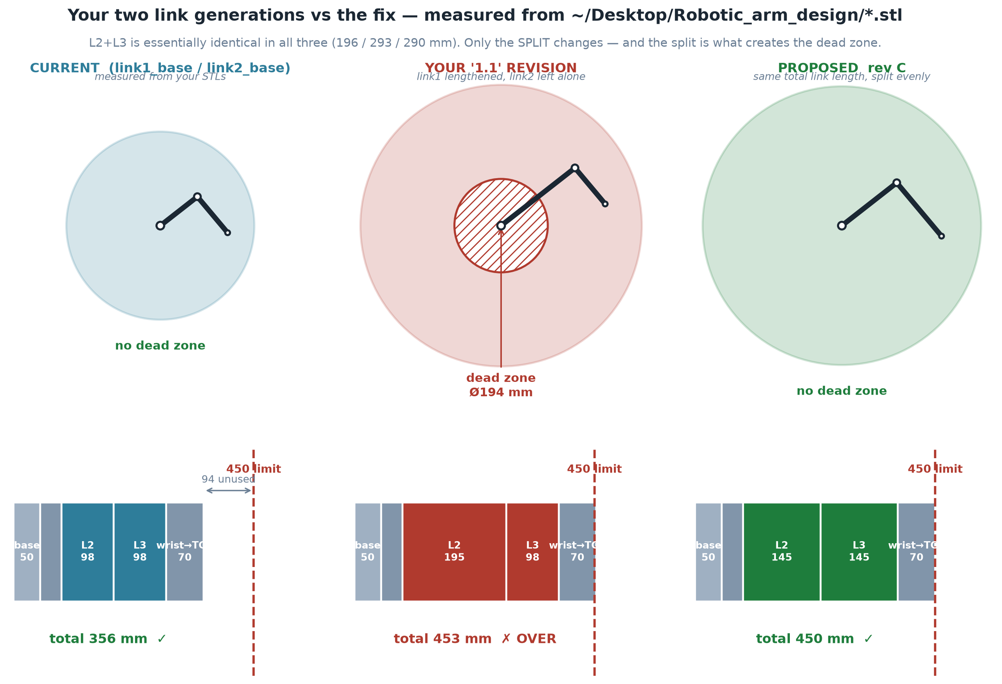
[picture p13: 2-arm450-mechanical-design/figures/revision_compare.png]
Revision comparison


| Configuration | L2 | L3 | Dead zone | Total length |
| --- | --- | --- | --- | --- |
| As printed | 97.9 | 97.9 | none | 356 mm |
| Revision 1.1 | 195.1 | 97.9 | **Ø194 mm** | 453 mm — over |
| **Recommended** | **145** | **145** | **none** | **450 mm** |

---

## 5. Measured link geometry

Joint centres were recovered by fitting circles to the end bosses (`measure_joint_centres.py`), because the bounding box overstates the kinematic length by the sum of the two boss radii.

| Part | Envelope length | Boss radius A | Boss radius B | **Joint-to-joint** |
| --- | --- | --- | --- | --- |
| link1_base | 147.5 | 25.2 | 25.0 | **97.9** |
| link2_base | 147.5 | 25.2 | 25.0 | **97.9** |
| link1_base_1.1 | 256.0 | 29.5 | 29.2 | **195.1** |
| link1_cover | 196.5 | 16.8 | 17.6 | 167.6 |
| link2_cover | 146.5 | 18.2 | 17.2 | 115.9 |
| link1_cover1.1 | 256.0 | 27.1 | 27.1 | 196.0 |

**Flag:** `link1_cover` (envelope 196.5) does not pair with `link1_base` (envelope 147.5). `link2_cover` (146.5) does pair with `link2_base` (147.5). Check this before reprinting — a mismatched shell pair is a likely cause of both the assembly gaps and any URDF export errors.

---

## 6. Link cross-section

| Property | Value |
| --- | --- |
| Outer width × depth | 47.5 × 29.0 |
| Wall thickness, as printed | 2.0 |
| Wall thickness, recommended | **2.4** (6 × 0.4 mm nozzle passes) |
| Second moment of area I, closed, t=2.0 | 39,899 mm⁴ |
| Torsion constant J, closed, t=2.0 | 83,267 mm⁴ |
| Torsion constant J, **seam open** | 661 mm⁴ — a 126× loss |

---

## 7. Part drawings by group

### Base

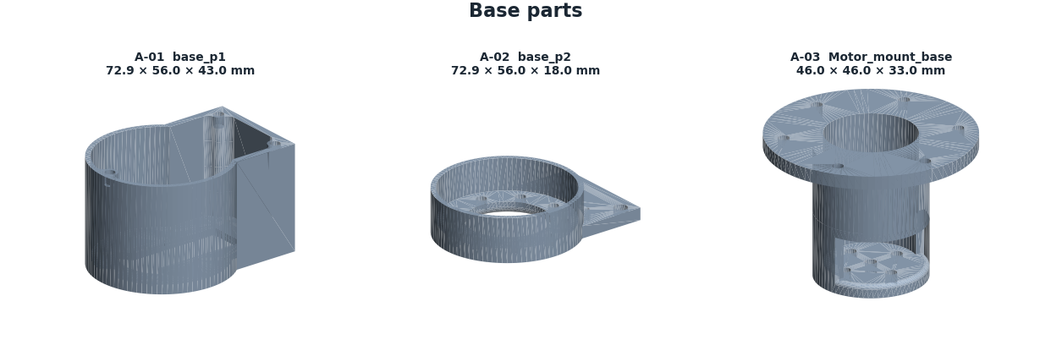
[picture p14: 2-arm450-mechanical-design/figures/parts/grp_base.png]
Base parts


| Part | Envelope (mm) | Wall | Status |
| --- | --- | --- | --- |
| A-01 base_p1 | 72.9 × 56.0 × 43.0 | 2.7 | keep |
| A-02 base_p2 | 72.9 × 56.0 × 18.0 | 2.8 | keep |
| A-03 Motor_mount_base | 46.0 × 46.0 × 33.0 | 2.3 | revise |

### Link

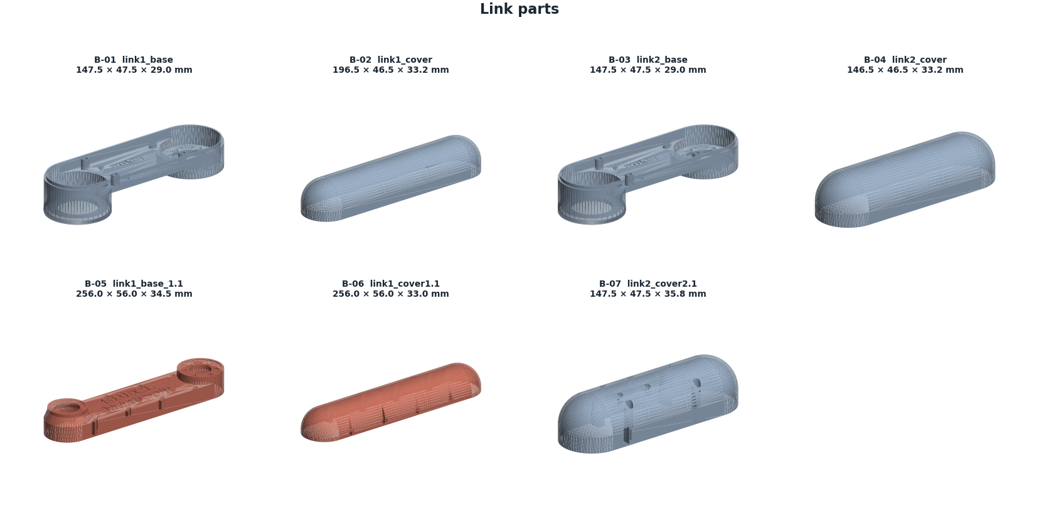
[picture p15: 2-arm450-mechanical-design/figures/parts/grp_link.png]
Link parts


| Part | Envelope (mm) | Wall | Status |
| --- | --- | --- | --- |
| B-01 link1_base | 147.5 × 47.5 × 29.0 | 2.0 | LENGTHEN |
| B-02 link1_cover | 196.5 × 46.5 × 33.2 | 2.2 | MISMATCH |
| B-03 link2_base | 147.5 × 47.5 × 29.0 | 2.0 | LENGTHEN |
| B-04 link2_cover | 146.5 × 46.5 × 33.2 | 1.9 | LENGTHEN |
| B-05 link1_base_1.1 | 256.0 × 56.0 × 34.5 | 2.7 | REJECT |
| B-06 link1_cover1.1 | 256.0 × 56.0 × 33.0 | 2.1 | REJECT |
| B-07 link2_cover2.1 | 147.5 × 47.5 × 35.8 | 1.9 | keep |

### Joint

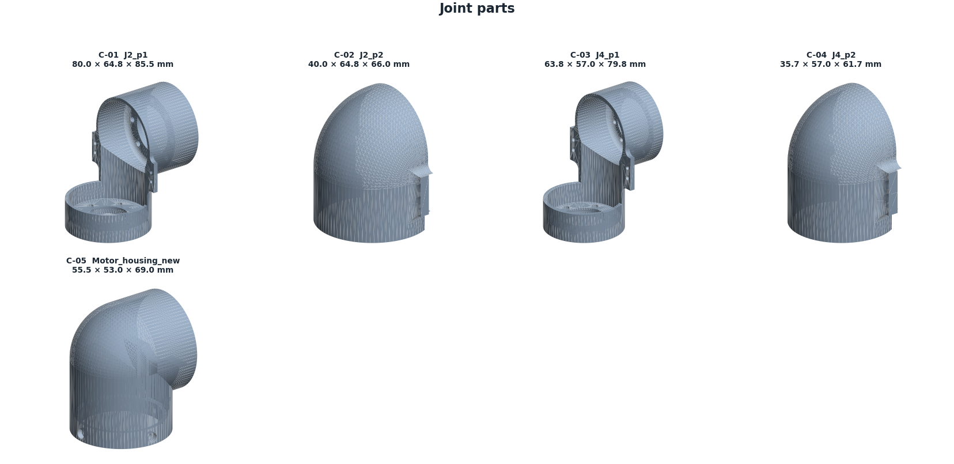
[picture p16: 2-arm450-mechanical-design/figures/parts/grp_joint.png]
Joint parts


| Part | Envelope (mm) | Wall | Status |
| --- | --- | --- | --- |
| C-01 J2_p1 | 80.0 × 64.8 × 85.5 | — | revise |
| C-02 J2_p2 | 40.0 × 64.8 × 66.0 | 2.0 | revise |
| C-03 J4_p1 | 63.8 × 57.0 × 79.8 | — | revise |
| C-04 J4_p2 | 35.7 × 57.0 × 61.7 | 2.2 | revise |
| C-05 Motor_housing_new | 55.5 × 53.0 × 69.0 | 2.6 | keep |

### Wrist

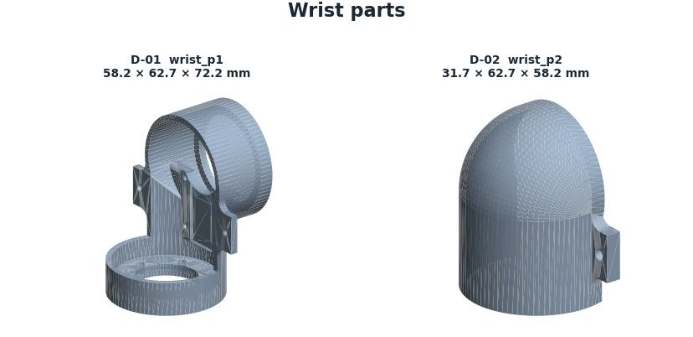
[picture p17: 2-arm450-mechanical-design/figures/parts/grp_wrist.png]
Wrist parts


| Part | Envelope (mm) | Wall | Status |
| --- | --- | --- | --- |
| D-01 wrist_p1 | 58.2 × 62.7 × 72.2 | 2.5 | keep |
| D-02 wrist_p2 | 31.7 × 62.7 × 58.2 | 2.2 | keep |

### Mount

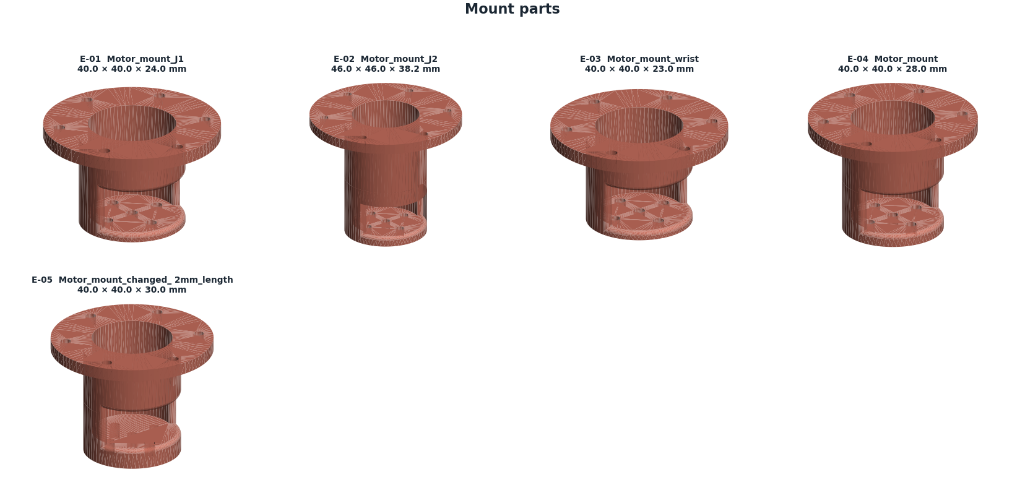
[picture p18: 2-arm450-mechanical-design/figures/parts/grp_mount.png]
Mount parts


| Part | Envelope (mm) | Wall | Status |
| --- | --- | --- | --- |
| E-01 Motor_mount_J1 | 40.0 × 40.0 × 24.0 | 2.1 | REDESIGN |
| E-02 Motor_mount_J2 | 46.0 × 46.0 × 38.2 | 2.3 | REDESIGN |
| E-03 Motor_mount_wrist | 40.0 × 40.0 × 23.0 | 2.1 | REDESIGN |
| E-04 Motor_mount | 40.0 × 40.0 × 28.0 | 2.2 | REDESIGN |
| E-05 Motor_mount_changed_ 2mm_length | 40.0 × 40.0 × 30.0 | 2.4 | REDESIGN |

### Fixer

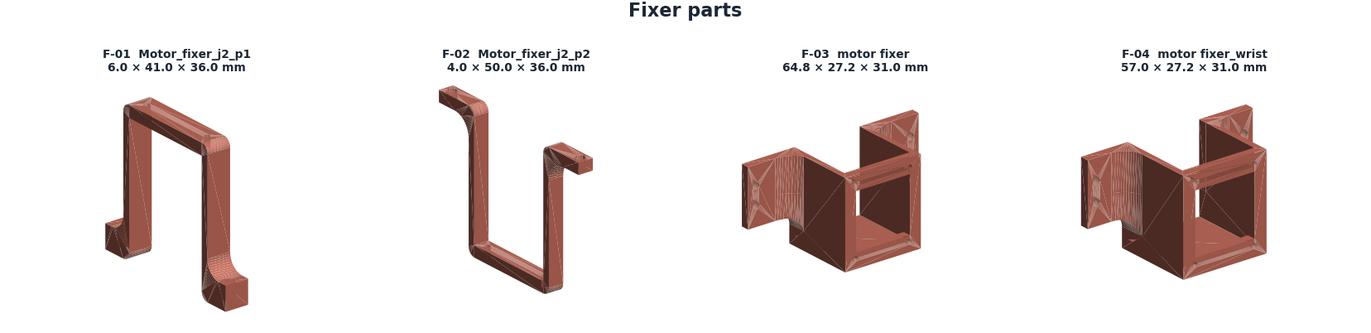
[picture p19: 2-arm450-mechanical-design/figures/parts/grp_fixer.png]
Fixer parts


| Part | Envelope (mm) | Wall | Status |
| --- | --- | --- | --- |
| F-01 Motor_fixer_j2_p1 | 6.0 × 41.0 × 36.0 | 1.7 | FAILS |
| F-02 Motor_fixer_j2_p2 | 4.0 × 50.0 × 36.0 | 1.4 | FAILS |
| F-03 motor fixer | 64.8 × 27.2 × 31.0 | 2.2 | FAILS |
| F-04 motor fixer_wrist | 57.0 × 27.2 × 31.0 | 2.1 | FAILS |

### COTS

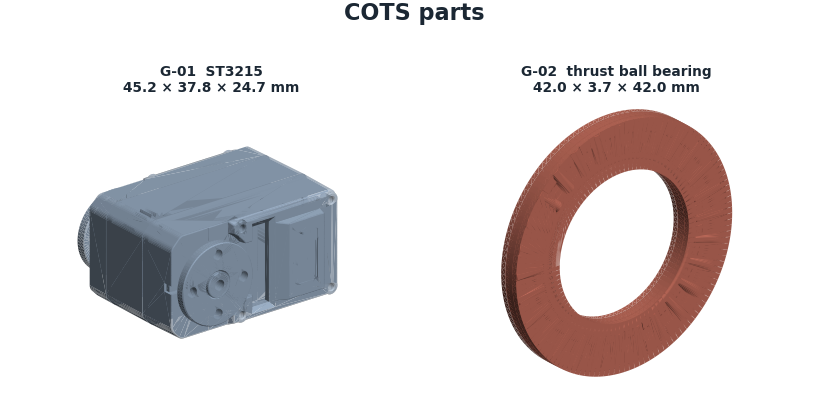
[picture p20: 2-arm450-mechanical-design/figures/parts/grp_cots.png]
COTS parts


| Part | Envelope (mm) | Wall | Status |
| --- | --- | --- | --- |
| G-01 ST3215 | 45.2 × 37.8 × 24.7 | 4.3 | COTS |
| G-02 thrust ball bearing | 42.0 × 3.7 × 42.0 | — | REPLACE |

### Tool

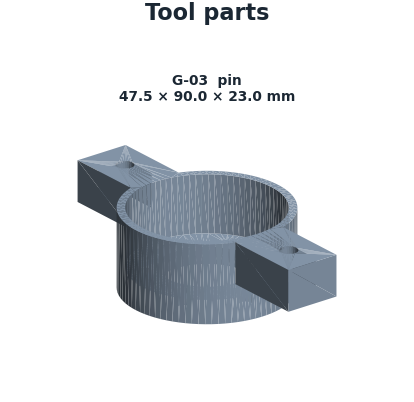
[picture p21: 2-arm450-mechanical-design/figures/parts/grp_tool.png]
Tool parts


| Part | Envelope (mm) | Wall | Status |
| --- | --- | --- | --- |
| G-03 pin | 47.5 × 90.0 × 23.0 | 2.9 | keep |

---

## 8. Critical interface dimensions

These are the dimensions that decide whether the arm assembles tightly. They matter more than any outside dimension.

| Interface | Current | Specify | Reason |
| --- | --- | --- | --- |
| Bearing pocket, Ø42 bearing | Ø42.0 modelled | **Ø42.15** press fit | FDM pockets print 0.1–0.4 mm undersize |
| Bearing pocket chamfer | none | **0.5 × 45°** | bearing starts square |
| Bearing axial seat | flat face | **turned shoulder** | flat printed faces are not flat |
| Bearing spacing per joint | ~5 (stacked) | **≥ 40** | moment stiffness ∝ spacing² |
| M3 heat-set insert hole | — | **Ø4.0** | for a Ø4.6 × 5.8 insert |
| Insert boss outer diameter | — | **≥ Ø9.0** | ≥ 2.2 mm wall or it splits |
| Seam fastener pitch | — | **≤ 25** | keeps the section closed |
| Seam interlock lip | none | **1.5 mm tongue-and-groove** | shear in bearing, not friction |
| Internal fillet radius | ~0 sharp | **≥ 2.0** | drops Kt from ≥3 to ~1.3 |
| Servo clamp form | 4–6 mm bracket | **full-perimeter collar, 4 mm wall** | carries torque in shear, not bending |

Insert dimensions are typical values — check your specific insert's datasheet.

---

## 9. Bill of materials — non-printed

| Item | Qty | Note |
| --- | --- | --- |
| Feetech ST3215 servo (30 kgf·cm) | 5 | J1, J3, J4, J5, J6 |
| Feetech ST3250 servo (50 kgf·cm) | 1 | J2 shoulder — needs the extra torque |
| Deep-groove ball bearings | 12 | 2 per joint, spaced ≥ 40 mm |
| M3 heat-set inserts, Ø4.6 × 5.8 | ~40 | seam and mounts |
| M3 socket-head screws, 8–16 mm | ~40 | |
| M3 preload screw + spacer per joint | 6 | removes bearing clearance |

Bearing sizes are not yet fixed — they depend on the shaft diameter chosen for each joint. See the open questions in the analysis report.

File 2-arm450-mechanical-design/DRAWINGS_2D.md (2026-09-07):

# ARM-450 — 2D Drawing Package

- **Project:** ARM-450, 6-DOF articulated arm, 450 mm overall
- **Date:** 2026-08-19
- **Units:** millimetres. Third-angle projection.
- **Source:** every view is projected from the exported CAD solid, not sketched.

---

## 1. Assembly specification

| parameter | value |
| --- | --- |
| Degrees of freedom | 6, all revolute |
| Overall length, fully extended | **450.0 mm** |
| Horizontal reach from the J1 axis | **360.0 mm** |
| Workspace volume | 118 litres |
| Workspace dead zone | **none** (measured min radius 0.3 mm) |
| Task workspace, pen normal to a vertical board | **52.3 %** |
| Rated payload | 300 g at the TCP |
| Absolute accuracy (predicted) | 1.4 mm RMS, 2.1 mm at 95 % |
| Repeatability, unidirectional approach | 0.70 mm RMS |
| Structural material | PLA+CF, 2.4 mm flange / 1.6 mm web |
| Assembled mass | **1297 g — see §5, over the 1200 g budget** |

### Actuator — Waveshare ST3215 (datasheet values)

| parameter | value |
| --- | --- |
| Case | 45.22 × 24.72 × 37.25 mm |
| **Output axis position** | **10.11 mm from one end — NOT centred** |
| Horn disc | Ø19.2 mm |
| **Horn bolt circle** | **Ø14.0 mm, 4 holes** |
| Stall torque | 30 kgf·cm = 2.942 N·m @ 12 V |
| Locked-rotor current | 2.7 A → 32.4 W, all heat |
| Torque constant kt | 11 kgf·cm/A = 1.079 N·m/A |
| Encoder | 360° magnetic, 4096 counts = **0.0879°** |
| Gear | metal; **no backlash figure published** |

**The off-centre output axis is the single most consequential number here.** Every
servo pocket was originally cut centred on its joint axis, which would have placed
every servo **12.50 mm out of position** with the horn nowhere near the bearing bore.

Applying the shift then exposed a second problem: the displaced pocket **overhung the
round housings** — by 7.3 mm on the J4 housing and 9.3 mm on the J6 output — so the
servo would have stuck out through the wall. Both housings are now **racetrack-shaped**:
a circle at the bearing axis extended along +X to swallow the servo. That costs nothing
in the 450 mm chain because it grows perpendicular to it.

| housing | was | now | servo containment |
| --- | --- | --- | --- |
| `wrist_j4_housing` | Ø56 circle | 65.7 × 54.0 racetrack | 2.39 mm margin |
| `wrist_j6_output` | Ø52 circle | 63.7 × 49.9 racetrack | 2.40 mm margin |
| `turret_j1` | Ø80 circle | unchanged | 4.69 mm margin |

### Common joint interface

Every joint uses the same three components, so a fit validated on one is valid on all six:

| item | specification |
| --- | --- |
| Bearing pocket | **Ø42.00 mm** modelled — gives 0.02 mm interference on a 0.02 mm-shrink printer |
| Bearing | **6806-2RS** deep groove, 30 × 42 × 7 — **12 off**, C2 preferred |
| Seat shoulder | Ø38.0 mm, outer race lands on it |
| Pocket chamfer | 0.5 × 45° at the mouth |
| Shaft | **Ø30 mm, steel tube, 5 mm wall** |
| Bearing spacing | 22 mm centre-to-centre |
| Preload | M3 screw drawing the inner races together |

---

## 2. Joint definition

| joint | type | axis | range | servo | worst-case torque | % of stall |
| --- | --- | --- | --- | --- | --- | --- |
| **J1** | revolute | Z (vertical) | ±165° | ST3215 | 0.000 N·m | gravity cannot load it |
| **J2** | revolute | Y (pitch) | ±115° | ST3215 | 2.625 N·m | 89 % |
| **J3** | revolute | Y (pitch) | ±150° | ST3215 | 1.271 N·m | 43 % |
| **J4** | revolute | Z (roll) | ±165° | ST3215 | 0.296 N·m | 10 % |
| **J5** | revolute | Y (pitch) | ±110° | ST3215 | 0.297 N·m | 10 % |
| **J6** | revolute | Z (roll) | ±175° | ST3215 | 0.088 N·m | 3 % |

**All six joints take the same Waveshare ST3215 (30 kgf·cm).** The 89 % figure at J2 applies only to 300 g at full extension; with a pen it falls to 14–29 %.

### Link dimensions

| segment | length |
| --- | --- |
| Base height | 50 mm |
| Base top → J2 (shoulder rise) | 40 mm |
| J2 → J3 (upper arm) | 119 mm |
| J3 → J4 (forearm) | 119 mm |
| J4 → J5 | 62 mm |
| J5 → J6 | 30 mm |
| J6 → TCP | 30 mm |
| **TOTAL** | **450 mm** |

---

## 3. Fastener schedule

| location | fastener | qty | note |
| --- | --- | --- | --- |
| Link seam | M3 × 12 into heat-set inserts | 12 per link | pitch ≤ 25 mm |
| Link tip ears | M2.5 into heat-set inserts | 2 per link | closes the seam at the bearing |
| Servo collar clamp | M3 × 16 | 2 per collar | |
| Servo case mounting | M2.5 | 4 per servo | pitch not dimensioned on the outline sheet |
| Servo horn | M2 | 4 per joint | **Ø14.0 BCD, datasheet** |
| Wrist inter-part | M3 | 4 per interface | Ø34 bolt circle |
| Tool flange | M3 | 4 | Ø30 bolt circle |
| Base foot | M4 | 4 | Ø104 bolt circle |
| Bearing preload | M3 + spacer | 1 per joint | **the single most important fastener** |

Insert bosses: **Ø9.5 outer minimum**, Ø4.1 hole, 7.5 mm deep for a Ø4.6 × 5.8 insert.

---
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

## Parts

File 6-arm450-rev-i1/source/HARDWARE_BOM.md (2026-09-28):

# ARM-450 rev I -- bought hardware (counted from the placed assembly)

| item | qty |
|---|---|
| 6706 bearing (30x37x4) | 4 |
| 6806 bearing (30x42x7) | 6 |
| M2.5 heat-set insert | 2 |
| M2.5 x 16 socket head | 2 |
| M2.5 x 6 socket head (horn) | 24 |
| M3 heat-set insert | 55 |
| M3 nyloc nut | 4 |
| M3 x 10 socket head | 12 |
| M3 x 12 socket head | 16 |
| M3 x 16 socket head | 10 |
| M3 x 20 socket head | 1 |
| M3 x 4 set screw | 1 |
| M3 x 45 socket head | 16 |
| M4 heat-set insert | 4 |
| M4 x 12 socket head | 4 |
| M5 x 10 set screw (cup point) | 8 |
| ST3215 servo | 6 |
| extension spring J2 (7.4 N @ 36.0 / 12.4 N @ 58.2 mm, inside hooks) | 2 |
| extension spring J3 (2.2 N @ 43.0 / 5.0 N @ 91.4 mm, inside hooks) | 2 |
| self-tapping screw ~2.2 x 8 pan head (from the servo box) | 20 |

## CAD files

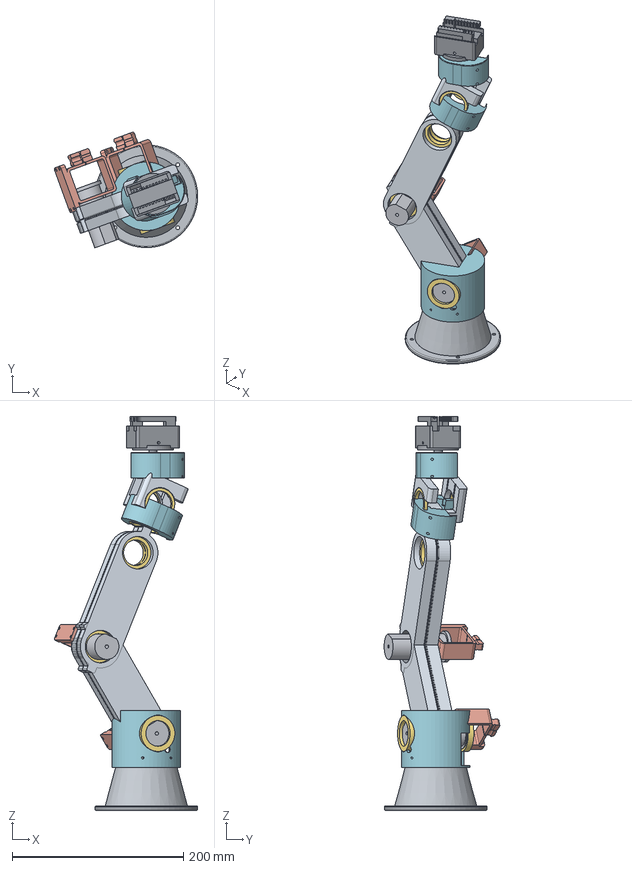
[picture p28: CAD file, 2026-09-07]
2-arm450-mechanical-design/output/cad/arm450_assembly_working.step
167.4 x 135.2 x 460.2 mm
base
bearing_6806_J1_base_1 x 9
turret_j1
link_half_groove_L2 x 2
link_half_tongue_L2 x 2
joint_shaft_L2 x 2
shaft_clamp_L2 x 2
servo_collar_J2 x 2
wrist_j4_housing
bearing_6706_J4_1 x 4
wrist_j5_yoke
wrist_j6_output
tool_adapter
tool_gripper
gripper_jaw_1 x 2

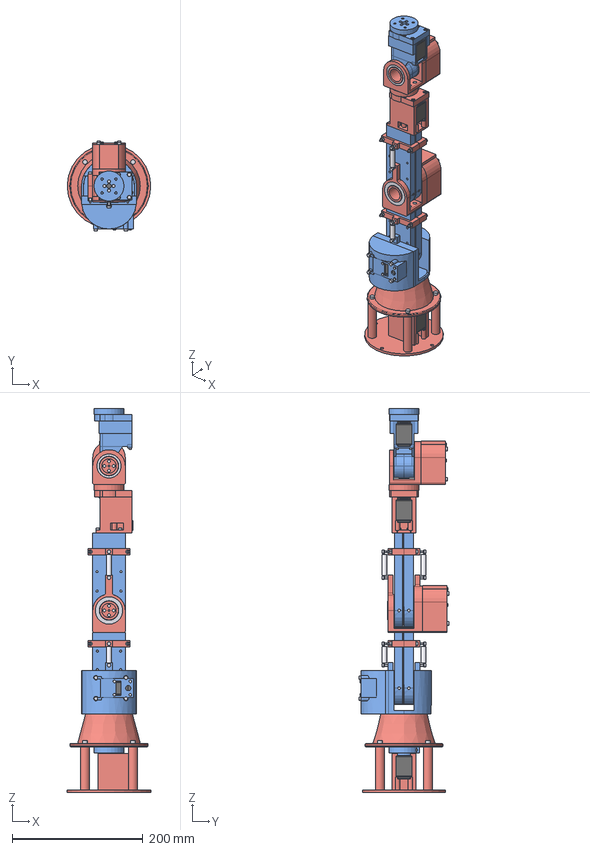
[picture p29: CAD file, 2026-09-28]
6-arm450-rev-i1/release/EDITABLE_CAD/assembly_step/ARM450_ASSEMBLY.step
128.0 x 137.8 x 588.4 mm
base
j1_mount
servo_J1 x 6
servo_scr_J1_0 x 20
brg_J1_z3 x 6
m4_base_foot_0
foot_ins_0
m4_base_foot_1
foot_ins_1
m4_base_foot_2
foot_ins_2
m4_base_foot_3
foot_ins_3
spigot_collar
j1_hub
J2_turret_p1
J2_turret_p2
horn_screw_J1_0 x 24
split_J2_0
split_ins_J2_0
split_J2_1
split_ins_J2_1
split_J2_2
split_ins_J2_2
split_J2_3
split_ins_J2_3
collar_pinch
collar_ins
pin_J2_turret_-1
pin_J2_turret_-1_ins
pin_J2_turret_+1
pin_J2_turret_+1_ins
spring_J2_-1
spring_J2_+1
J2_shaft
link_upper_groove
link_upper_tongue
shaft_clamp_1
shaft_clamp_2
J3_p1
J3_p2
collar_upper_+y
collar_upper_-y
split_J3_0
split_ins_J3_0
split_J3_1
split_ins_J3_1
split_J3_2
split_ins_J3_2
split_J3_3
split_ins_J3_3
j3fork_link_0
link_end_ins_0
j3fork_link_1
link_end_ins_1
j3fork_link_2
link_end_ins_2
j3fork_link_3
link_end_ins_3
seam_upper_0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

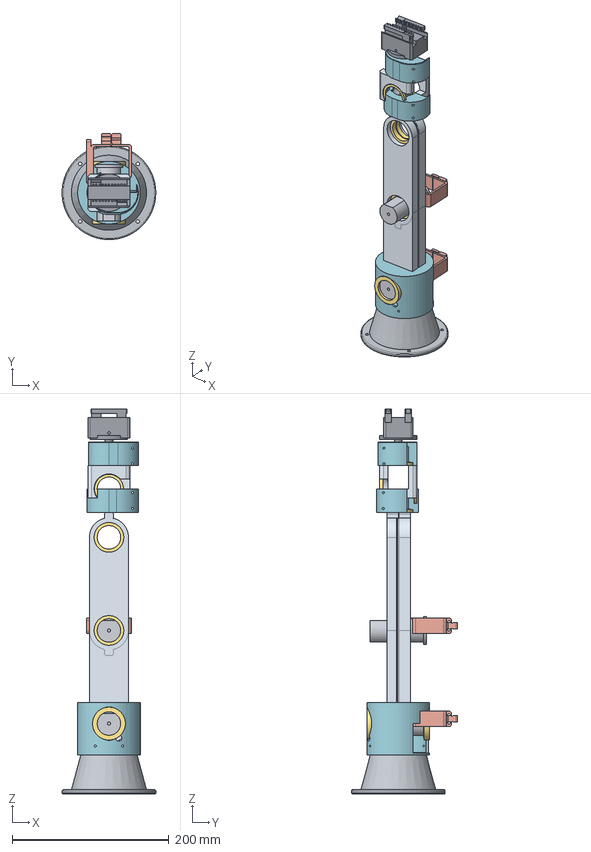
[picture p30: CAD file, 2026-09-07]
2-arm450-mechanical-design/output/cad/arm450_assembly_home.step
119.9 x 135.8 x 492.0 mm
base
bearing_6806_J1_base_1 x 9
turret_j1
link_half_groove_L2 x 2
link_half_tongue_L2 x 2
joint_shaft_L2 x 2
shaft_clamp_L2 x 2
servo_collar_J2 x 2
wrist_j4_housing
bearing_6706_J4_1 x 4
wrist_j5_yoke
wrist_j6_output
tool_adapter
tool_gripper
gripper_jaw_1 x 2

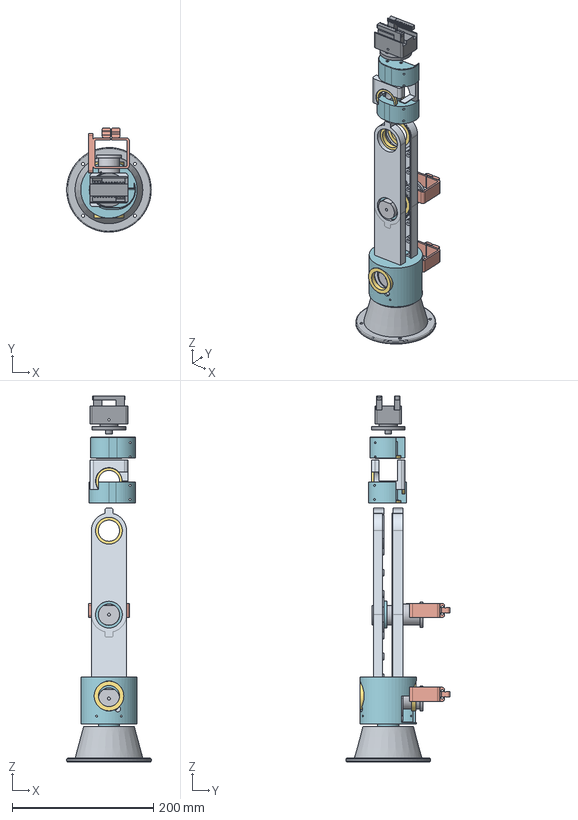
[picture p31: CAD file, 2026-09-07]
2-arm450-mechanical-design/output/cad/arm450_assembly_exploded.step
119.9 x 147.8 x 519.0 mm
base
bearing_6806_J1_base_1 x 9
turret_j1
link_half_groove_L2 x 2
link_half_tongue_L2 x 2
joint_shaft_L2 x 2
shaft_clamp_L2 x 2
servo_collar_J2 x 2
wrist_j4_housing
bearing_6706_J4_1 x 4
wrist_j5_yoke
wrist_j6_output
tool_adapter
tool_gripper
gripper_jaw_1 x 2

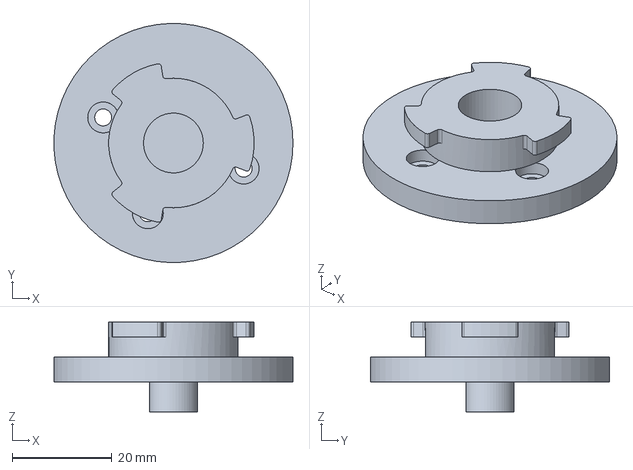
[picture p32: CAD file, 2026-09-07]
2-arm450-mechanical-design/output/cad/tool_adapter.step
48.0 x 48.0 x 18.0 mm

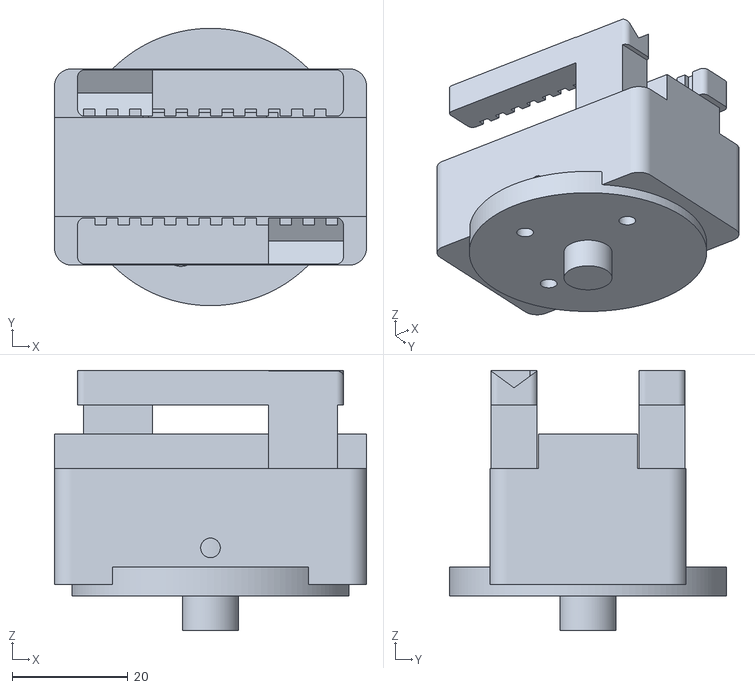
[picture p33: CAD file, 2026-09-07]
2-arm450-mechanical-design/ros2/arm450_description/meshes/tool_gripper.stl
54.0 x 48.0 x 45.0

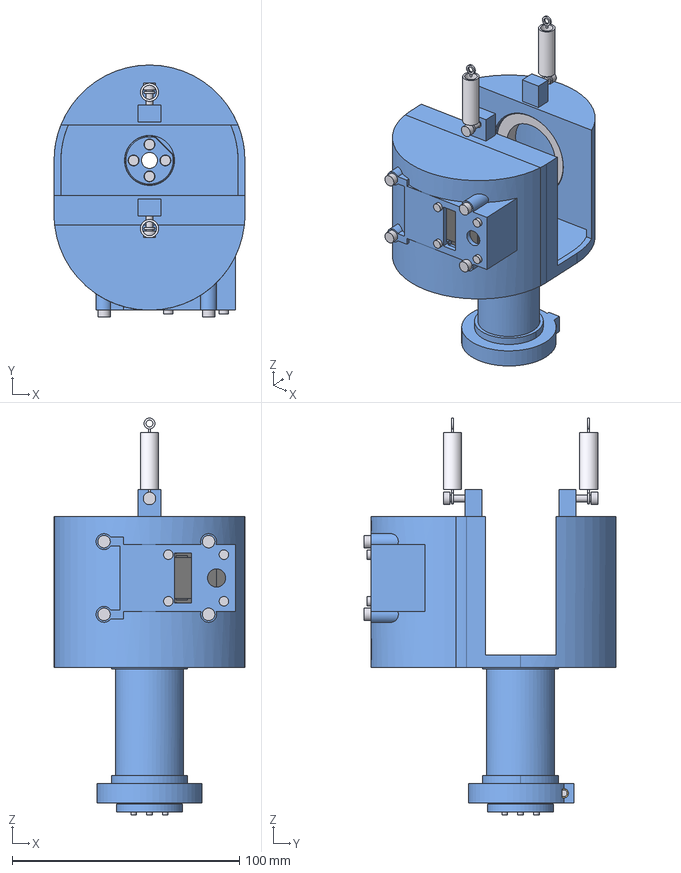
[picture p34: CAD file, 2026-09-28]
6-arm450-rev-i1/release/EDITABLE_CAD/assembly_step/body_turret.step
84.0 x 110.9 x 174.7 mm
spigot_collar
j1_hub
J2_turret_p1
J2_turret_p2
servo_J2
servo_scr_J2_0 x 4
brg_J2_drive x 2
horn_screw_J1_0 x 4
split_J2_0
split_ins_J2_0
split_J2_1
split_ins_J2_1
split_J2_2
split_ins_J2_2
split_J2_3
split_ins_J2_3
collar_pinch
collar_ins
pin_J2_turret_-1
pin_J2_turret_-1_ins
pin_J2_turret_+1
pin_J2_turret_+1_ins
spring_J2_-1
spring_J2_+1

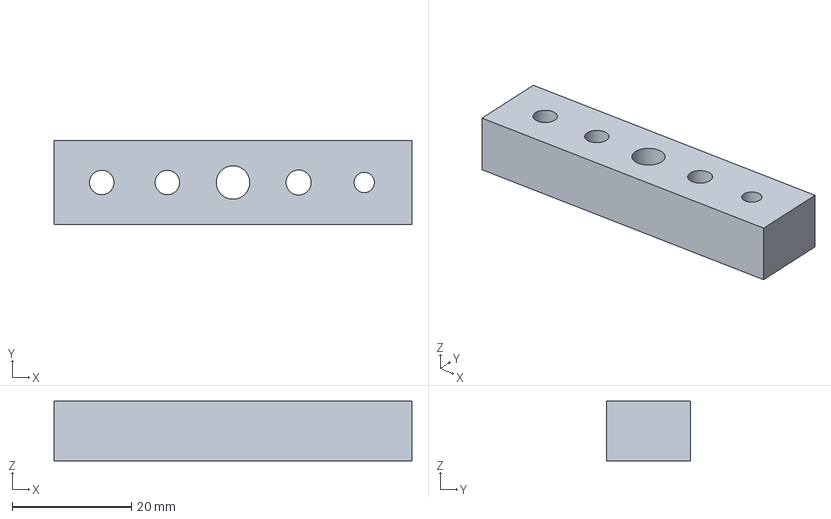
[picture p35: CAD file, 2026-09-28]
6-arm450-rev-i1/release/EDITABLE_CAD/fit_test_step/fit_06_holes.step
60.0 x 14.0 x 10.0 mm

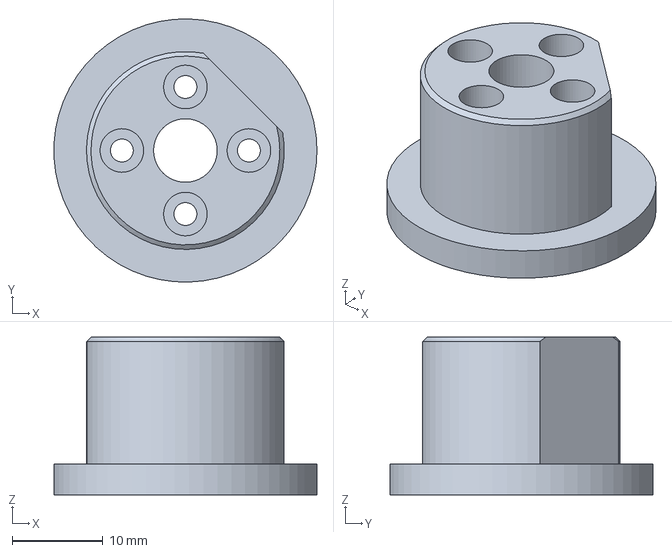
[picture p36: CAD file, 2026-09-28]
6-arm450-rev-i1/release/EDITABLE_CAD/parts_step/04_j1_hub_x1.step
29.0 x 29.0 x 17.4 mm

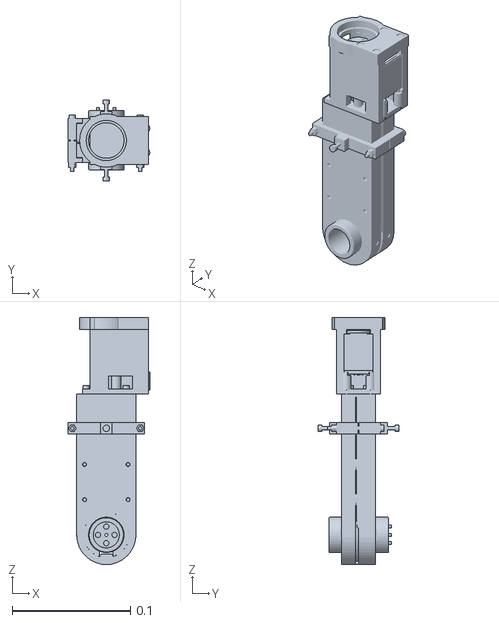
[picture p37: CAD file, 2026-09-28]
6-arm450-rev-i1/release/EDITABLE_CAD/urdf/meshes/forearm.stl
0.0689 x 0.068 x 0.209

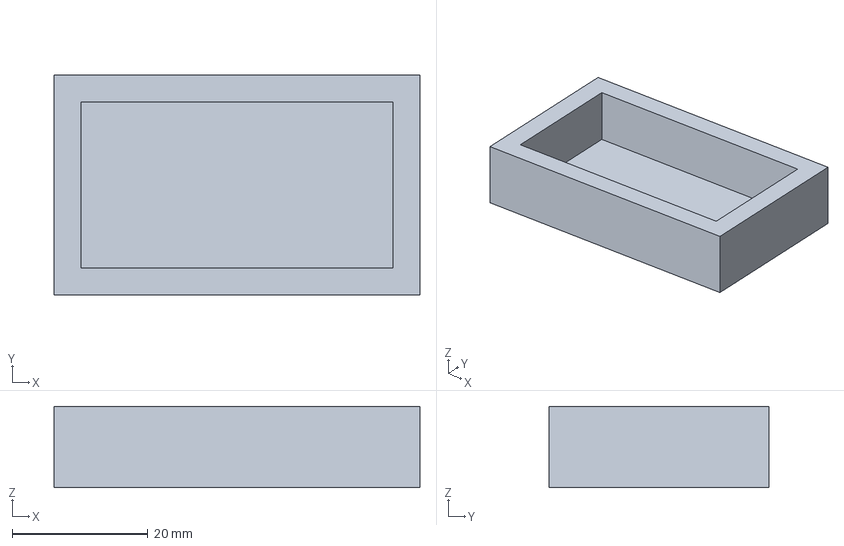
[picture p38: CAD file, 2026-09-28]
6-arm450-rev-i1/release/FUSION_DESIGN_TREES/fit_test/fit_01_servo_pinch/fit_01_servo_pinch_released.step
54.0 x 32.5 x 12.0 mm

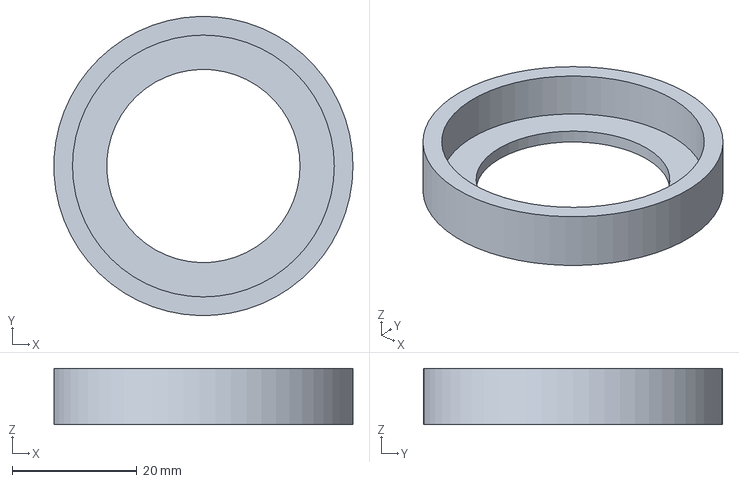
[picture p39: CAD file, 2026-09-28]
6-arm450-rev-i1/release/FUSION_DESIGN_TREES/fit_test/fit_02_6806_seat/fit_02_6806_seat_released.step
48.0 x 48.0 x 9.00 mm

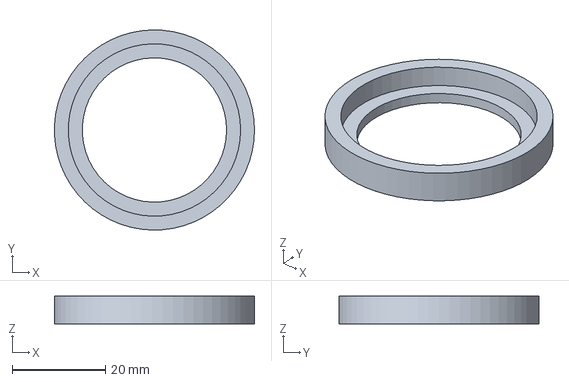
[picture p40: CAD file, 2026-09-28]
6-arm450-rev-i1/release/FUSION_DESIGN_TREES/fit_test/fit_03_6706_seat/fit_03_6706_seat_released.step
43.0 x 43.0 x 6.00 mm

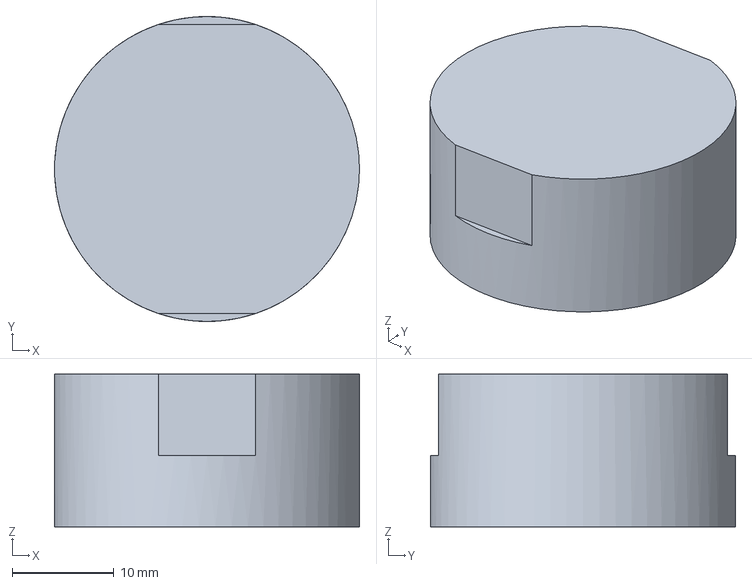
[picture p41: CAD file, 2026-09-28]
6-arm450-rev-i1/release/FUSION_DESIGN_TREES/fit_test/fit_04_shaft_stub/fit_04_shaft_stub_released.step
29.9 x 29.9 x 15.0 mm

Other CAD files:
6-arm450-rev-i1/release/FUSION_DESIGN_TREES/fit_test/fit_05_centring_ring/fit_05_centring_ring_released.step
6-arm450-rev-i1/release/FUSION_DESIGN_TREES/parts/01_base_x1/01_base_x1_released.step
6-arm450-rev-i1/release/FUSION_DESIGN_TREES/parts/02_spigot_collar_x1/02_spigot_collar_x1_released.step
2-arm450-mechanical-design/output/cad/arm450_parts_kit.step
2-arm450-mechanical-design/output/cad/base.step
2-arm450-mechanical-design/output/cad/base.stl
2-arm450-mechanical-design/output/cad/bearing_6706.step
2-arm450-mechanical-design/output/cad/bearing_6706.stl
2-arm450-mechanical-design/output/cad/bearing_6806.step
2-arm450-mechanical-design/output/cad/bearing_6806.stl
2-arm450-mechanical-design/output/cad/bearing_yoke.step
2-arm450-mechanical-design/output/cad/bearing_yoke.stl
2-arm450-mechanical-design/output/cad/dock_target.step
2-arm450-mechanical-design/output/cad/dock_target.stl
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

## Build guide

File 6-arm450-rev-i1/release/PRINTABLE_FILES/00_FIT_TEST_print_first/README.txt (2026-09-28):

FIT TEST -- print these first (about 1.5 h, ~40 g). Every dimension below is
taken from the design constants, so a coupon that fits means the real parts
fit on YOUR printer. If a fit is tight or loose, set your slicer's XY hole /
contour compensation (or tell me the numbers and the parts are regenerated).

  fit_01_servo_pinch   24.50 x 46.02 slot, 10 deep: the ST3215 must slide in
                       with a firm push and hold by friction (design -0.22 mm)
  fit_02_6806_seat     O42.00 x 7 pocket: a 6806 presses in by thumb/vice
  fit_03_6706_seat     O37.02 x 4 pocket: a 6706 presses in
  fit_04_shaft_stub    O29.95 x 15 shaft, one double-D flat pair (28.40 across):
                       slides through a 6806 / 6706 bore
  fit_05_centring_ring O38.35 / O30.0 x 5 slice of the link ring: slides on the
                       stub and into your printed link's O38.4 bore
  fit_06_holes         O4.1 (M3 insert) x2, O5.6 (M4 insert), O4.2 (M5 self-tap),
                       O3.4 (M3 clearance): set an insert, run an M5 in
  fit_07_servo_screws  a copy of a servo cover's back: 4 pads + O3.4 holes on
                       the servo's back-hole pattern (Waveshare drawing: 8.30 /
                       32.75 from the output shaft, 20.5 across). Lay it on
                       the BACK of your servo (the pads on the flat around the
                       4 holes, the wire slot under the window) and drive the
                       4 self-tapping screws from the servo box: they must line
                       up, bite, and pull the plate down flat without bottoming
                       out (2.6 mm go into the servo). If the holes do not line
                       up, STOP and tell me -- every servo mount uses them.

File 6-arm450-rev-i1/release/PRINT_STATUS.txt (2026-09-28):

ARM-450 rev I.1 -- PRINT STATUS (verification audit 2026-09-24, J3_p1 lug fix re-verified 2026-09-27)

PRINT VERDICT: GREEN. Print the fit test first (7 coupons, about 2 h); when coupon 07 screws onto the back of your servo, print all 27 files. Every check is at 0 after M1 (servos screwed by their own holes), M2 (wire windows) and M3 (Rule 8: every servo seated on 4 supports, heads beside turning links sunk, cable route proven); wiring verified against your photo.

PRINT ORDER:
  1. 00_FIT_TEST_print_first -- FIRST, all 7 coupons (07 = the servo-screw plate)
  2. then all 27 files in PRINTABLE_FILES (33 pieces); the 6 servo housings (03_j1_mount, 06_J2_turret_p2, 13_J3_p2, 18_j4_base, 22_J5_p2, 25_j6_body) once coupon 07 has screwed onto your servo's back

Why and what changed: ARM450_AUDIT_REPORT.pdf

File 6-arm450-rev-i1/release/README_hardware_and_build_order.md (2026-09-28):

# ARM-450 rev I.1 -- print-ready files

**PRINT STATUS (2026-09-24 audit, J3_p1 re-verified 2026-09-27): see `PRINT_STATUS.txt`. Print the fit test
first; when coupon 07 screws onto the back of your servo, print everything.**

## rev I.1 (2026-09-27): reprint `12_J3_p1` only

Your slicer view was right: the two J3 spring lugs stood on the round cheek tops joined
by a 0.1 mm sliver (corners 0.4 mm in the air). They are now sunk 1.5 mm into the cheeks
and blended in by R3 webs (joint area 34 -> 136 mm2). Every other file is unchanged.

Every STL in `STL_print_ready/` is already rotated to its checked print
orientation and set on the bed. Print the quantity in the file name.
`STEP_design_frame/` holds the same parts in their design frame.

## Print the fit test FIRST (`00_FIT_TEST_print_first/`, about 2 h)

Coupon 07 is a copy of a servo cover's back: lay it on the BACK of a servo and drive the
4 self-tapping screws from the servo box -- they must line up, bite and pull it flat.
If they do not line up, stop: every servo mount uses these holes.
The key fits are finer than an FDM printer's accuracy (+-0.1..0.2 mm): bearing
seats O42.00 / O37.02, printed shafts O29.95 in 30 mm bores, the -0.22 mm servo
pinch, the 0.025 mm centring-ring fit. The six coupons carry exactly those fits.
Print them with the settings you will use for the arm; if a bearing does not press
in, a shaft does not slide or the servo rattles, tune the slicer's XY hole / contour
compensation (or tell me the measured numbers) before printing the big parts.

## Changed by the 2026-09-24 audit (reprint these if you printed the earlier set)

`j1_mount` (idler-horn pocket, 4 table holes, end wall 7.0), `base` (foot floor 3.0 mm),
`spigot_collar`, `J3_p2`, `J5_p2` (2.4 mm shell round the bay), `J5_shaft` (flat to
the idle end), `j4_base` (idler-horn pocket), `j4_cap`, `j6_body`, `j6_cap`,
`shaft_clamp`, `link_fore_tongue`, `link_fore_groove`, `link_upper_tongue` (cable skin
1.2 mm); servo-screw pads / posts / bridge and new wire windows in `j1_mount`,
`J2_turret_p2`, `J3_p2`, `J5_p2`, `j4_base`, `j6_body`. `ARM450_AUDIT_REPORT.pdf` says why.

## Print list

| file | qty | orientation used | supports | size (mm) | note |
|---|---|---|---|---|---|
| `01_base_x1.stl` | 1 | +Z up | REQUIRED | 120 x 120 x 50 | rev I: lower 6806 pocket opens from underneath |
| `02_spigot_collar_x1.stl` | 1 | +Z up | none | 46 x 46 x 12 | split clamp + J1 collet closer, slot 2.0, 1 x M3 pinch bolt |
| `03_j1_mount_x1.stl` | 1 | +Z up | none | 128 x 128 x 70 | J1 servo mount + the arm's foot |
| `04_j1_hub_x1.stl` | 1 | +Z up | advised | 29 x 29 x 17 | J1 horn coupler, D-keys the turret |
| `05_J2_turret_p1_x1.stl` | 1 | +X up | REQUIRED | 138 x 70 x 84 | turret; spigot end slit as a collet (J1 zero play); land on the 6806 inner ring only |
| `06_J2_turret_p2_x1.stl` | 1 | -Y up | advised | 83 x 66 x 37 | J2 servo pod (2.4 shell round the whole servo), 4 x M3x45 split bolts |
| `07_J2_shaft_x1.stl` | 1 | +Y up | none | 30 x 30 x 50 | printed J2 shaft, bolts to the horn; double-D flats for the M5 set screws |
| `08_shaft_clamp_x4.stl` | 4 | -Z up | none | 37 x 38 x 14 | link centring ring (0.025 fits); links locked by 2 x M5 set screws each |
| `09_link_upper_groove_x1.stl` | 1 | +Z up | advised | 110 x 50 x 14 | released, unchanged (reuse your printed one) |
| `10_link_upper_tongue_x1.stl` | 1 | +Z up | advised | 110 x 50 x 16 | rev I: released + head counterbores (or drill yours: O6.0x3.2 seam, O5.0x2.7 ear) |
| `11_collar_upper_x2.stl` | 2 | +Z up | none | 64 x 24 x 10 | J2 spring collar, print 2 (same part) |
| `12_J3_p1_x1.stl` | 1 | -Z up | REQUIRED | 98 x 50 x 53 | J3 fork; J3 spring lugs (both pockets) |
| `13_J3_p2_x1.stl` | 1 | -Z up | none | 72 x 50 x 37 | J3 servo cradle, bay 34.99 deep, 2.4 back wall |
| `14_J3_shaft_x1.stl` | 1 | -Z up | none | 30 x 30 x 50 | printed J3 shaft, double-D flats for the M5 set screws |
| `15_link_fore_tongue_x1.stl` | 1 | +Z up | advised | 144 x 50 x 16 | rev I forearm: socket end, valid solid, flush seam-screw heads |
| `16_link_fore_groove_x1.stl` | 1 | +Z up | advised | 144 x 50 x 14 | rev I forearm: socket end, valid solid |
| `17_collar_fore_x2.stl` | 2 | +Z up | none | 64 x 24 x 10 | J3 spring collar, print 2 (same part) |
| `18_j4_base_x1.stl` | 1 | -Z up | REQUIRED | 57 x 38 x 65 | J4 servo base; lip tops relieved off the 6706 inner ring |
| `19_j4_cap_x1.stl` | 1 | -Z up | none | 58 x 45 x 10 | J4 cap, holds the 6706 |
| `20_j4_hub_x1.stl` | 1 | -Z up | none | 46 x 46 x 20 | J4 hub, carries the J5 fork |
| `21_J5_p1_x1.stl` | 1 | +X up | advised | 48 x 50 x 66 | J5 fork |
| `22_J5_p2_x1.stl` | 1 | -Z up | none | 66 x 50 x 37 | J5 servo cradle, bay 34.99 deep, 2.4 back wall |
| `23_J5_shaft_x1.stl` | 1 | -Z up | none | 30 x 30 x 45 | printed J5 axle |
| `24_J5_spacer_x2.stl` | 2 | +Z up | none | 32 x 32 x 3 | blade spacers, exactly 3.0 (close the J5 stack), print 2 |
| `25_j6_body_x1.stl` | 1 | -X up | REQUIRED | 43 x 54 x 87 | J5 blade + J6 servo housing |
| `26_j6_cap_x1.stl` | 1 | -X up | none | 45 x 58 x 10 | J6 cap, holds the 6706 |
| `27_j6_flange_x1.stl` | 1 | -X up | none | 46 x 46 x 20 | tool flange, bolts to the J6 horn |

**Supports:** 'REQUIRED' = touching build plate is enough except J2_turret_p1 and
J3_p1 (bearing pockets): use everywhere. 'advised' = small overhangs, supports
make them cleaner. Forearm/upper link halves print flat, web down, with
build-plate supports (same as the released link halves).

**Suggested settings (PETG or PLA+):** 0.2 mm layers, 4 perimeters, 40 %
gyroid infill; shafts, hubs and the tool flange 100 % infill (they carry
the joint torque). Heat-set inserts after printing.

## Bought hardware

| item | qty |
|---|---|
| item | qty |
|---|---|
| 6706 bearing (30x37x4) | 4 |
| 6806 bearing (30x42x7) | 6 |
| M2.5 heat-set insert | 2 |
| M2.5 x 16 socket head | 2 |
| M2.5 x 6 socket head (horn) | 24 |
| M3 heat-set insert | 55 |
| M3 nyloc nut | 4 |
| M3 x 10 socket head | 12 |
| M3 x 12 socket head | 16 |
| M3 x 16 socket head | 10 |
| M3 x 20 socket head | 1 |
| M3 x 4 set screw | 1 |
| M3 x 45 socket head | 16 |
| M4 heat-set insert | 4 |
| M4 x 12 socket head | 4 |
| M5 x 10 set screw (cup point) | 8 |
| ST3215 servo | 6 |
| extension spring J2 (7.4 N @ 36.0 / 12.4 N @ 58.2 mm, inside hooks) | 2 |
| extension spring J3 (2.2 N @ 43.0 / 5.0 N @ 91.4 mm, inside hooks) | 2 |
| self-tapping screw ~2.2 x 8 pan head (from the servo box) | 20 |

Plus the six ST3215 servos' own horn screws are replaced by the M2.5 x 6 above.
Every screw above was placed in the model and checked as a solid: runs free in its
hole, engages its insert / nut / horn >= 3 mm (M3), head seated, tip clear of the
pocket floor (`REV_H/FASTENER_CHECK.log`). Lengths are standard sizes -- do not
substitute longer ones: several would bottom out.

## Your already-printed upper link

The released **groove** half is reused as printed. The **tongue** half needs flush
screw heads (its outer face runs 1.0 mm from the turret cheek, a standard head
stands 3 mm proud and jams J2). Either print the rev-I tongue in this folder, or
counterbore yours by hand from the OUTER face: O6.0 x 3.2 mm deep on the four
O3.4 seam holes, O5.0 x 2.7 mm on the ear hole next to the clamp bore.

## Assembly notes that matter

* Link lock (J2, J3): before assembly, run an M5 screw into each link half's two
  O4.2 side holes (90/270 deg) to form the thread. Slide a centring ring into each
  half with its gap over the seam ear, put the link on the shaft, then drive the
  2 x M5 x 10 cup-point set screws per half through the side holes onto the shaft's
  two flats. Zero play; the ring only centres.
* Fork floors (J3 fork on the upper link, J5 fork on the J4 hub): 4 x M3 x 10 each, heads
  sunk in the floor's counterbores (they sit under the swinging link / blade).
* J1: the spigot end is slit (a collet). Tighten the spigot-collar pinch bolt LAST,
  after the hub is on the horn: it closes the spigot onto the hub plug.
* J5: the two 3.0 mm spacers close the blade stack between the inner rings with no
  play; if a print is thick, sand the spacer until the axle slides home.
* Bearings (J2, J3, J5 drive side): each presses into its pocket from the fork gap
  and is held by that press fit (seat O42.00 / O37.00, measured); the floor behind it
  stands 0.5 mm clear, so it never touches either ring. Add a drop of bearing-
  retaining compound (e.g. Loctite 641) on the outer ring so it cannot creep.
* J2/J3/J5 servo covers (p2) close with 4 x M3 x 45 each into p1's inserts.
* EVERY SERVO IS SCREWED BY ITS OWN BACK HOLES with the self-tapping screws from its
  box (~8 mm; 2.6 mm go into the servo -- a longer screw needs a washer). J2/J3/J5: 4
  through the cover, heads on its outer face, after the M3 x 45s. J1: 4 from UNDER the
  foot plate, before the foot goes on the table. J4: 2 from under the J4 base plate (in
  the finished arm the forearm spring collars cover them). J6: 2 through the bridge over
  the servo's far end, on the bench before the blade goes into the J5 fork.
* J5 axle: its flat runs out of the idle end; turn the flat to the blade's D-bore
  and slide it in from the idle side (checked free both ways, in and out).
* Fix the foot to the table: at full reach the arm's centre of mass is 118 mm from
  the J1 axis, the foot's radius is 64 mm -- unfixed, it tips. Drive 4 x M5 bolts
  (or #10 wood screws) through the O5.5 holes in the foot plate BEFORE the base goes
  on (the base covers them), or clamp the foot plate to the table.
* The real ST3215 has a O19.2 idler horn on its back face that turns with the
  output. The J1 foot, the J4 base and the J6 body have a O20.4 pocket for it; the
  fork bays J2/J3/J5 clear it by 0.95 mm. Keep the pocket clean of stringing.
* Servo cables: both bus sockets sit in a slot across the servo's back face, 11.7-16.7 mm
  from the output axis (manufacturer's model, matches your photo). Plug both cables in
  BEFORE closing a cover: J2/J3/J5 wires leave straight out through the 12 x 20 window
  in the cover (1.05 mm to spare), J1/J4/J6 wires run along the channel under the servo
  (checked: REV_H/WIRING_CHECK.log). Leave a service loop at every joint.
* Plug slots: every plug can go in and out with the arm assembled (REV_H/PLUG_INSERT.log):
  J2/J3/J5 straight through the cover window; J1/J4 lift it 10 mm, move it a few mm to
  the side, then out past the open end of the servo channel; J6 lift 14 mm, then out
  sideways. Long-nose pliers help at J1/J4/J6.
* Temperature: the J2 servo runs near its continuous rating in a closed pod. Read the
  ST3215 temperature register in your control code and back off if it climbs.
* Heat-set inserts: every pocket is sized for 4.1 mm OD x 5.7 mm M3 inserts
  (M4: 5.6 x 8; M2.5 ear insert: 3.5 x 4).

## Cables: one joint per cable, nothing can wind up

The bus is a daisy chain (controller -> J1 -> ... -> J6). Each cable crosses ONE joint -- the
one driven by the servo it leaves -- and no joint turns more than 180 deg in total, so a cable
only flexes back and forth. Leave the loop below at each joint and tie the cable down on both
sides of it (REV_H/CABLE_ROUTE.log):

```
  cable      crosses range        exit r from axis         span min..max (mm)     change     loop / cable
  J1 -> J2   J1      +-90.0       40.0 mm (bound   80)      144.6 .. 179.0         34.5 mm    54 / 263 mm
  J2 -> J3   J2      +-54.0       14.8 mm (bound   24)      184.1 .. 200.7         16.6 mm    37 / 267 mm
  J3 -> J4   J3      +-72.0       14.8 mm (bound   28)      141.6 .. 155.1         13.5 mm    33 / 219 mm
  J4 -> J5   J4      +-90.0       40.0 mm (bound   80)      106.8 .. 148.4         41.6 mm    62 / 240 mm
  J5 -> J6   J5      +-46.5       14.8 mm (bound   21)       74.6 .. 85.3          10.7 mm    31 / 146 mm
  J6 is the last servo on the bus: no cable leaves it
```

## Gravity springs (buy to these two points each)

Lengths are **inside the hooks** (on the O3 pins; pin centre to pin centre is 3.0 mm less).
A spring with initial tension is fine as long as it passes through both points.

* J2 x2: **7.4 N at 36.0 mm** and **12.4 N at 58.2 mm** inside hooks (rate 0.224 N/mm)
* J3 x2: **2.2 N at 43.0 mm** and **5.0 N at 91.4 mm** inside hooks (rate 0.056 N/mm)
* each hooks over an M3 x 12 screw in a heat-set insert, 5 mm spacer under the hook

## What the springs buy -- and the limit

Arm held level, worst case over the whole J2 x J3 range, ST3215 continuous
0.88 N.m: J2 0.824 N.m (SF 1.07), J3 0.701 N.m (SF 1.26). **The arm moves
itself; it is not rated for a payload held continuously** (your choice:
simple springs, no payload).

## Build sequence (the order every screw was checked to be reachable in)

 1. foot: J1 servo into the foot, its 4 screws from under the foot plate
 2. J1 hub onto the horn
 3. base + J1 bearings onto the foot
 4. turret p1 + J2 bearings, spigot collar
 5. BENCH upper link
 6. BENCH J2 servo + shaft
 7. JOIN link into the J2 gap, servo+shaft down the axis
 8. J2 pod on, servo screws, link set screws
 9. J3 fork p1 onto the upper link
10. BENCH forearm
11. BENCH J4 base on the forearm
12. BENCH J4 servo (2 screws from under the plate), bearing, cap
13. BENCH J4 hub onto the horn
14. BENCH J5 fork p1 onto the hub
15. BENCH blade: J6 servo, bearing, cap
16. BENCH blade: tool flange onto the J6 horn
17. BENCH J5 servo + axle
18. JOIN blade into the J5 gap, spacers, axle down the axis
19. J5 cover, servo screws, axle grub
20. BENCH J3 servo + shaft
21. JOIN forearm into the J3 gap, servo+shaft down the axis
22. J3 cover, servo screws, link set screws
23. spring collars
24. spring pins + springs

BENCH = done on the table as a sub-assembly; JOIN = the sub-assemblies go together.
Two of the four base->foot M4 bolts sit under the J2 servo pod at J1 = 0: to service
them later turn J1 to +45 (bolt 2) or -45 deg (bolt 3) -- measured, TOOL_ACCESS.log.

## Degrees of freedom

Six: J1 base yaw, J2 shoulder, J3 elbow, J4 forearm roll, J5 wrist pitch, J6 tool roll
(spherical wrist). Checked in `REV_H/DOF6_CHECK.log`: each axis measured from the servo
horn AND from its bearing pockets (they coincide), Jacobian rank 6 over the working range.
Swept ranges without a clash: J1 +-90, J2 +-54, J3 +-72, J4 +-90, J5 +-46.5, J6 +-90 deg.
Straight up (the modelled home) is singular, as for any arm of this layout; park and
start from a bent 'ready' pose (e.g. J2 30, J3 -60, J5 30).

## Verification behind this folder

* drive trains J1..J6, bearings as solids, shaft clamps, every fastener, springs,
  whole-arm motion, print gates: FAILURES per stage = 0, 0, 0, 0, 0, 0, 0
* static all-pairs interference: CLASHES (penetration >= 0.15 mm) -- must each be explained:
* manual check by slicing each joint: TOTAL CLASHES IN THE SECTIONS: 0
* parameter -> CAD audit: 265 parameters measured back out of these files, 0 fail
* manufacturer's ST3215 STEP in all six seats: OFFICIAL-SERVO CHECK: 0 problem
* assembly / disassembly paths (both servo models): DISASSEMBLY PATHS: 0 blocked, DISASSEMBLY PATHS: 0 blocked
* joints together, tipping, thin walls, bed: JOINTS TOGETHER: 0 pair(s) too close, TIPPING: 0 problem(s), THIN WALLS: 0 part(s) with a thin wall, BED: 0 part(s) too big for a 180 mm cube
* see `REV_H/REVI_CHECKS.log`, `REV_H/PARAM_AUDIT.md`, `REV_H/ARM450_REV_I_FINAL.pdf`

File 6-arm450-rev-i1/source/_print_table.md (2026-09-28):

| `j1_mount` | 1 | +Z up | none |
| `j1_hub` | 1 | +Z up | advised |
| `J2_turret_p1` | 1 | +X up | REQUIRED |
| `J2_turret_p2` | 1 | -Y up | advised |
| `J2_shaft` | 1 | +Y up | none |
| `J3_p1` | 1 | +Y up | REQUIRED |
| `J3_p2` | 1 | -Z up | none |
| `J3_shaft` | 1 | -Z up | none |
| `link_fore_tongue` | 1 | +Z up (flat, web down) | REQUIRED (touching build plate) |
| `link_fore_groove` | 1 | +Z up (flat, web down) | REQUIRED (touching build plate) |
| `j4_base` | 1 | -Z up | advised |
| `j4_cap` | 1 | -Z up | none |
| `j4_hub` | 1 | -Z up | none |
| `J5_p1` | 1 | +X up | advised |
| `J5_p2` | 1 | -Z up | none |
| `J5_shaft` | 1 | -Z up | none |
| `J5_spacer` | 2 | +Z up | none |
| `j6_body` | 1 | -X up | advised |
| `j6_cap` | 1 | -X up | none |
| `j6_flange` | 1 | -X up | none |

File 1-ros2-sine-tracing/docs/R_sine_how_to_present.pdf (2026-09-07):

# R_sine — How to Present to Your Guide

A slide-by-slide speaking script, likely questions with answers, and presentation tips. Read this once before you present; keep it beside you during.

### Before you start — 7 tips

- Total time: aim for 8–10 minutes of talking, then questions. About 40 seconds per slide.
- Open with the goal and the demo picture so the guide sees the result first, then explain how.
- Lead with your OWN work (the DH derivation, the Jacobian, the IK); mention ikpy only as a check.
- When a slide shows numbers, say the one-line takeaway ('matches to machine precision'), not every digit.
- Point at the figure while you talk — the drawn sine and the workspace are your strongest visuals.
- If you don't know an answer, say what you'd do to find out — that reads as maturity, not weakness.
- Keep the live RViz demo command ready as a backup: ros2 launch Rsine rsine_sine.launch.py

### Slide-by-slide script

Slide 1 R_sine — Drawing a Sine Wave with a myCobot 280

Say: Start here. 'My project makes a 6-DOF myCobot 280 arm draw a sine wave on a board. What makes it rigorous is that I derived the kinematics myself using the modified DH method from our course, built the Jacobian by velocity propagation, and solved the inverse kinematics with damped least squares — then I verified every piece against an independent library. It all runs in ROS 2.'

If asked: Why a sine wave?
Answer: It is a smooth, continuously-curving path that exercises all axes and makes tracking accuracy easy to see — a good test of the full FK/Jacobian/IK pipeline.

Slide 2 Objective and Method

Say: 'The project is built around the three standard problems: forward kinematics, the Jacobian, and inverse kinematics. I generate the sine as a list of 3D target points, solve inverse kinematics for each point to get joint angles, and play that back on the robot.'

If asked: What is the difference between forward and inverse kinematics?
Answer: Forward: joints -> pose (one unique answer). Inverse: pose -> joints (can have several answers or none if unreachable).

Slide 3 Modified (Craig) DH Convention

Say: 'I use the modified DH convention from class. Each joint is described by four numbers — twist, length, offset, and angle — and each link transform is this product of a rotation and translation about x then z. Multiplying them gives the forward kinematics.'

If asked: Why modified DH and not standard DH?
Answer: Modified DH places the frame at the proximal joint, which many textbooks (Craig) use; it is the convention in my reference notes. Both are valid.

Slide 4 Identified DH Table (verified to 1e-15 m)

Say: 'This table is the heart of the model. The official URDF doesn't come with DH parameters, so I identified them by fitting the four numbers per joint until my DH forward kinematics matched the URDF exactly — the error is 1e-15 meters, essentially machine zero. So the table is provably correct, not guessed.'

If asked: How do you know the table is right?
Answer: Its forward kinematics matches the manufacturer URDF to ~1e-15 m over 5000 random joint configurations, and also matches ikpy to ~1e-16 m.

Slide 5 Forward Kinematics

Say: 'Forward kinematics is just the product of the six link transforms. Here's the arm at its home pose with the frame at every joint. When I feed the same joints to ikpy, it lands on the identical position — so my FK is correct.'

If asked: What frame is the tool?
Answer: link6_flange — the output flange where a pen or gripper mounts.

Slide 6 Jacobian — Velocity Propagation

Say: 'For the Jacobian I used the velocity-propagation method from the notes — you push the angular and linear velocity outward joint by joint. For revolute joints it simplifies to this cross-product form. I checked it against a numerical Jacobian and it agrees to seven decimal places.'

If asked: What is the Jacobian used for here?
Answer: It drives the inverse kinematics — each IK step multiplies a damped inverse of J by the pose error to update the joint angles.

Slide 7 Reachable Workspace (verified)

Say: 'This is the reachable workspace — every point the tool can reach — from three views. The red sine is my drawing target, and you can see it sits comfortably inside. This is also how I chose where to put the board: somewhere the arm can comfortably reach.'

If asked: Why not draw further out or on the table?
Answer: This is a small arm; keeping the pen perpendicular to a far or downward surface exceeds its reach. The vertical board close in is fully reachable.

Slide 8 Inverse Kinematics — Damped Least Squares

Say: 'I solve inverse kinematics with damped least squares. Each iteration nudges the joints by a damped inverse of the Jacobian times the pose error. The damping is what keeps it stable near singularities. It converges in about 16 steps per point and always respects the joint limits.'

If asked: Why damped, not the plain Jacobian inverse?
Answer: Near singularities the plain inverse blows up. Damping trades a negligible position error for numerical stability.

Slide 9 Configurable Drawing Plane

Say: 'The plane is general. I define it by an origin and two axes — one to advance along, one for the wave. The pen is kept perpendicular to the surface. So the same code draws on a vertical board or a flat plate; I just change the parameters at launch.'

If asked: Could it draw a different shape?
Answer: Yes — only the path generator changes; the FK/Jacobian/IK pipeline is the same.

Slide 10 Result — Drawing the Sine

Say: 'And here's the result — the arm drawing the two-cycle sine, shown as a progression. The red line is what the tool actually traces. It matches the intended curve to under a millimetre, and the pen stays perpendicular to the board the entire time.'

If asked: Is this simulation or the real robot?

Answer: Simulation in RViz with the exact robot model; the design is hardware-ready since it uses the real URDF joint names and limits.

Slide 11 Accuracy and Verification

Say: 'These are the numbers I'd stake the project on. Forward kinematics is exact to machine precision, the Jacobian to seven digits, and the drawn path tracks to about a micron. The error plot stays a thousand times under a millimetre.'

If asked: 0.001 mm seems too good — is it real?
Answer: It is the numerical tracking error of the solver in simulation. On real hardware, encoder resolution and calibration would dominate; this bounds the algorithm's own contribution.

Slide 12 Analytical vs ikpy

Say: 'Finally, a sanity check against an independent library, ikpy. Every comparison — forward kinematics, Jacobian, inverse kinematics — agrees far below a millimetre, and both methods draw the same sine. Two independent implementations agreeing is my strongest evidence the math is right.'

If asked: If ikpy exists, why write your own?
Answer: To understand and control the math, handle orientation and limits my way, and have a solver that matches the course methodology — with ikpy only as a check.

Slide 13 ROS 2 Architecture

Say: 'Software-wise, the math is in plain Python modules with no ROS, so I can unit-test them. Then two small ROS nodes: one streams the joint trajectory, the other records the drawn line. A single launch file brings up the robot and RViz.

If asked: Why precompute the trajectory instead of solving live?
Answer: The sine is fixed, so solving once and replaying is smooth and cheap; live IK would just repeat the same work every loop.

Slide 14 Conclusion and Future Work

Say: 'To conclude: I built the kinematics from scratch, verified every stage, and used it to draw a sine on a board in ROS 2. It generalizes to other surfaces and shapes. Next I'd move to the physical arm with a real pen and add Gazebo physics. Thank you — happy to take questions.'

If asked: What was the hardest part?
Answer: Identifying a correct, physically clean DH table from a URDF that isn't in DH form — solved by fitting and verifying to machine precision.

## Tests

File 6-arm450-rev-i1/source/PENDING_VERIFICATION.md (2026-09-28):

# Pending verification — J2 / J3 / J5 servo seating

**Status: NOT VERIFIED after five attempts.** Reported as unknown rather than
guessed. One hard result was obtained along the way (§3).

---

## 1. What IS established

**The bays are the right size.** Each part carries a parallel wall pair at
exactly the design bay dimension, located from the geometry itself:

| part | wall pair | axis | centre-line |
|---|---|---|---|
| `J2_turret_p1` | **BAY_L 46.00** | Y | −5.500 |
| `J3_p1` | **BAY_L 46.00** | Z | +5.500 |
| `J5_p1` | **BAY_W 38.00** | Z | −3.000 |
| `J5_p2` | **BAY_W 38.05** | Y | 0.000 |
| `J4_module` | **BAY_W 38.05** | Y | 0.000 |

Design: `BAY_L = 46.02`, `BAY_W = 38.05`. Match within 0.05 mm.

---

## 2. Five failed attempts, and why each was discarded

| # | method | why it was invalid |
|---|---|---|
| 1 | bounding-box void scan | these are open forks (16–30 % solid) so most "free space" is open air **outside** the part; the J3 "fit with 23.95 mm margin" was the servo floating beside it |
| 2 | full 3-axis search | timed out twice (exit 124, 143) |
| 3 | coarse 4 mm centre-line sweep | **failed its control** — missed J4, a bay known to seat the servo; 4 mm cannot land on 0.5 mm clearance and one axis range collapsed to empty |
| 4 | batched sweep | OOM-killed (exit 137), then hung: J2 alone needs **15 912** `contains()` calls on a 10 042-triangle mesh |
| 5 | derive pocket from its own faces | `contains()==0` also means **outside the part** — it "seated" J4 at z = −12.36 on a module spanning z 0…36.72. Adding a containment requirement fixed that, but floor selection still picks the wrong face: it returns (1.75, 0, 13.00) where the known-good J4 centre is (12.51, 0, 22.46) |

**Every attempt was caught by a control, not shipped.** Attempt 3 would have
reported three false defects.

---

## 3. One hard result: `J5_p2` cannot hold the servo

Settled by arithmetic, no probe required:

```
ST3215 case      45.22 x 37.80 x 24.72
J5_p2 bounding box   36.28 x 50.00 x 29.02
sorted: part 29.02 / 36.28 / 50.00   vs   servo 24.72 / 37.80 / 45.22
                      36.28 < 37.80  ->  short by 1.52 mm
```

The part is **1.52 mm too small in its second dimension**, so no orientation
fits. **The J5 servo is not in `J5_p2`** — it must be in `J5_p1`, whose box
(36.28 × 50.00 × 48.00) does accept the case.

---

## 4. Why J4 could be verified and these cannot, yet

J4's pocket origin is **derivable from its generator**: `rect(BAY_L, BAY_W)`
centred on `SERVO_AXIS_OFFSET`, floor at `J4_MOD_H − BAY_T`. Place the servo
there once: **0 of 3 324 points in material**, horn on the joint axis to
0.010 mm.

J2/J3/J5 are built by `fork()` in `fork_pro.py`, which computes the bay in a
local frame (`z_bay = z_in + SEAT_T + brg_w + FLOOR_T`) and then transforms it.
`SEAT_T`, `FLOOR_T` and `BACK_T` are not in `fixparams.py` — they come from
elsewhere in the import chain. **Recovering that chain is the remaining work**,
and it is a derivation, not a search.

---

## 5. Honest position

**Do not treat J2 / J3 / J5 servo fit as verified.** The bays are the right
size and there is no evidence of a J1-style defect — J1 failed because its pod
is a round *bore* where the far corner swings to r = 37.22 against a 35.70
bore, which cannot arise in a rectangular pocket. But "no evidence of a defect"
is not "verified to fit".

**`J5_p2` is a real finding** and should be treated as one: it cannot contain
the servo, so any documentation showing the J5 servo there is wrong.

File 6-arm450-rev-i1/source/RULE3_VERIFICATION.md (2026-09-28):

# ARM-450 rev H — Rule 3 verification

Every number measured from the solids or the user's own `Motor.stl`.
Nothing taken from a parameter file.

## What was wrong, and where it came from

One root cause explains the servo-mount failures at **all three** driven
joints. `fixparams` carries `SERVO_L/W/T = 45.22 / 37.25 / 24.72`, and every
generator derives its bay as

```
BAY_W = SERVO_W + 2*BAY_CLR   = 38.05
BAY_T = SERVO_T + BAY_CLR+1.5 = 26.62
```

But `BAY_T` is cut **along the servo's output axis**, and measured from the
mesh the ST3215 needs **33.50 mm** there — the 24.72 is the case *width*,
not its depth. So every bay was **6.88 mm too shallow** while `BAY_W` had
**13.33 mm of slop**: the servo would not go in, and could rattle if it did.

| joint | cavity as released | needed | short by |
|---|---|---|---|
| J2 turret | 27.11 | 33.50 | 6.39 |
| J3 elbow | no bay at all | 33.50 | — |
| J5 wrist | no usable bay | 33.50 | — |

## Fixes

* **J3** — regenerated through `fork_pro.fork_p1/p2` with the drive cheek
  intact and the bay from `servo_geom.py`.
* **J5** — **new design** (`gen_j5_new.py`). The old layout ran the 45.22 mm
  case along the one boxed-in direction (36.28 mm available). The new one
  copies J3's topology: case length **along the arm**, output axis across.
  **The arm stays 450 mm** — no link lengthening needed.
* **J2** — regenerated with the corrected bay, growing outward to
  y = −64.40. Verified free: `base` has no material at y < −45 in the
  bay's z band.
* **J4** — a 0.0198 mm floating disc (7.75 mm², a tenth of a layer) where
  blind inserts bottomed at 29.220 against a bore ceiling at 29.200.
  Insert depth 7.50 → 8.00.

## Rule 3, item by item

| # | requirement | result |
|---|---|---|
| 3 | pockets/holes/bores on the right face and plane | **PASS** — bearing pockets, horn bores and pinch channels measured on both forks |
| 2 | no thin surfaces near 0.1 mm | **PASS** — 0 sub-layer bands on every part |
| 4 | servo on the right face, driving the next link | **PASS** — horn on the joint axis to **0.0000 mm** at J2, J3, J5 |
| 5 | not floating, orientation locked | **PASS** — −0.22 mm pinch measured at 24.500; 5° rotation bites |
| 8 | screwdriver reach | **PASS** — all 12 fasteners, 70 mm clear run for a 6 mm driver |
| 8 | joint motion in sync | **PASS** — all 6 joints sweep full travel, 0 clashes |
| 9 | assemble / disassemble | **PASS** — two-piece housings, bolts accessible, no captive parts |
| 10 | no face overlap, real clearance | **PASS** — parting planes coincident to 0.000000, 0 interpenetration |
| 7 | wiring clearance | **PASS** — cable exit bored in the back wall of each bay |

### Manual verification (the most important check)
`manual_verify.py` slices each fork and reads the geometry feature by
feature. **ALL CHECKS PASS** on J3 and J5:
bearing pockets Ø42.15/Ø37.15 (want Ø42.02/Ø37.02), horn bores Ø24.13,
pinch channel 24.472 at every station, 0 sub-layer bands, horn offset
0.0000, contact only on the pinch faces, parting gap 0.000000.

### Motion sweep
All six joints, full travel, differential against the rest pose:
**0 joints with a real rise**. Validated with a control — an injected
block in the J3 arc was detected.

### Seated fits confirmed, not clashes
* J5/J4 mating face: 0.0000 z-spread, 0 points inside → coincident face.
* J1 hub/turret: r 10.92–11.00, a 0.08 mm shell → press fit.
* spigot/collar: bore r 15.035 vs spigot r 14.995 → **0.040 mm clearance**.

## Gate bugs found and fixed

Both thin-feature gates paired parallel planes on offset alone, ignoring
face direction and overlap — inventing findings on solid material. Fixed to
require opposed normals and real footprint overlap. **Validation held**:
both still catch the known-bad released `J4_module`, both still pass the
known-good `base`. False findings disproved by direct probing: `J5_p1`
"0.100 mm" (270 probe columns, 0 sub-layer runs) and `J4` "0.375 mm".

## PRINT GO

**GO — 15 parts, 0 findings on both gates:**

J2_turret_p1, J2_turret_p2, J3_p1, J3_p2, J4_module, J5_p1, J5_p2,
J5_strap, j1_clamp, j1_drive_hub, j1_pod, j3_clamp, j5_clamp,
servo_strap_micro, spigot_collar.

**One condition: the straps are not optional.** The pinch alone leaves
~2° of rotational play at each joint; the strap closes it. Print
`J5_strap` and use the existing `servo_strap` at J2/J3.

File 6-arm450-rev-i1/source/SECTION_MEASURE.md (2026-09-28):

# Manual verification by slicing -- measured in each joint's section

**Total clashes: 0**

## J1 base yaw  (cut: point (np.float64(0.0), np.float64(0.0), np.float64(0.0)), normal (np.float64(0.0), np.float64(1.0), np.float64(0.0)); 10 parts in the cut)

| part A | part B | overlap mm2 | overlap thickness | gap | verdict |
|---|---|---|---|---|---|
| J2_turret_p1 | base | 0.00 | 0.000 | 0.50 | gap 0.50 |
| J2_turret_p1 | brg_J1_z3 | 0.00 | 0.000 | 0.00 | contact |
| J2_turret_p1 | brg_J1_z43 | 0.00 | 0.000 | 0.00 | contact |
| J2_turret_p1 | j1_hub | 0.00 | 0.000 | 0.12 | gap 0.12 |
| J2_turret_p1 | spigot_collar | 0.00 | 0.000 | 0.07 | gap 0.07 |
| base | brg_J1_z3 | 0.00 | 0.000 | 0.00 | contact |
| base | brg_J1_z43 | 0.00 | 0.000 | 0.00 | contact |
| base | spigot_collar | 0.00 | 0.000 | 0.50 | gap 0.50 |
| brg_J1_z3 | spigot_collar | 0.00 | 0.000 | 0.00 | contact |
| horn_screw_J1_0 | j1_hub | 0.00 | 0.000 | 0.00 | contact |
| horn_screw_J1_0 | servo_J1 | 0.00 | 0.000 | 0.00 | contact |
| horn_screw_J1_180 | j1_hub | 0.00 | 0.000 | 0.00 | contact |
| horn_screw_J1_180 | servo_J1 | 0.00 | 0.000 | 0.00 | contact |
| j1_hub | j1_mount | 0.00 | 0.000 | 0.96 | gap 0.96 |
| j1_hub | servo_J1 | 0.00 | 0.000 | 0.00 | contact |
| j1_hub | spigot_collar | 0.00 | 0.000 | 0.76 | gap 0.76 |
| j1_mount | servo_J1 | 0.00 | 0.000 | 0.00 | contact |
| j1_mount | spigot_collar | 0.00 | 0.000 | 1.31 | gap 1.31 |

## J2 shoulder  (cut: point (np.float64(0.0), np.float64(0.0), np.float64(90.0)), normal (np.float64(0.0), np.float64(0.0), np.float64(1.0)); 16 parts in the cut)

| part A | part B | overlap mm2 | overlap thickness | gap | verdict |
|---|---|---|---|---|---|
| J2_shaft | J2_turret_p1 | 0.00 | 0.000 | 0.54 | gap 0.54 |
| J2_shaft | brg_J2_drive | 0.00 | 0.000 | 0.02 | gap 0.02 |
| J2_shaft | brg_J2_idle | 0.00 | 0.000 | 0.02 | gap 0.02 |
| J2_shaft | horn_screw_J2_0 | 0.00 | 0.000 | 0.00 | contact |
| J2_shaft | horn_screw_J2_180 | 0.00 | 0.000 | 0.00 | contact |
| J2_shaft | link_set_1_270 | 0.00 | 0.000 | 0.00 | contact |
| J2_shaft | link_set_1_90 | 0.00 | 0.000 | 0.00 | contact |
| J2_shaft | link_set_2_270 | 0.00 | 0.000 | 0.00 | contact |
| J2_shaft | link_set_2_90 | 0.00 | 0.000 | 0.00 | contact |
| J2_shaft | servo_J2 | 0.00 | 0.000 | 0.00 | contact |
| J2_shaft | shaft_clamp_1 | 0.00 | 0.000 | 0.79 | gap 0.79 |
| J2_shaft | shaft_clamp_2 | 0.00 | 0.000 | 0.79 | gap 0.79 |
| J2_turret_p1 | J2_turret_p2 | 0.00 | 0.000 | 0.00 | contact |
| J2_turret_p1 | brg_J2_drive | 0.00 | 0.000 | 0.00 | contact |
| J2_turret_p1 | brg_J2_idle | 0.00 | 0.000 | 0.00 | contact |
| J2_turret_p1 | link_upper_groove | 0.00 | 0.000 | 1.00 | gap 1.00 |
| J2_turret_p1 | link_upper_tongue | 0.00 | 0.000 | 1.00 | gap 1.00 |
| J2_turret_p1 | servo_J2 | 0.00 | 0.000 | 0.00 | contact |
| J2_turret_p2 | servo_J2 | 0.00 | 0.000 | 0.40 | gap 0.40 |
| horn_screw_J2_0 | servo_J2 | 0.00 | 0.000 | 0.00 | contact |
| horn_screw_J2_180 | servo_J2 | 0.00 | 0.000 | 0.00 | contact |
| link_set_1_270 | link_upper_groove | 3.96 | 0.397 | 0.00 | thread 0.40 (M5 set screw forms its thread in the link's O4.2 hole) |
| link_set_1_270 | shaft_clamp_1 | 0.00 | 0.000 | 0.20 | gap 0.20 |
| link_set_1_90 | link_upper_groove | 3.96 | 0.397 | 0.00 | thread 0.40 (M5 set screw forms its thread in the link's O4.2 hole) |
| link_set_1_90 | shaft_clamp_1 | 0.00 | 0.000 | 0.20 | gap 0.20 |
| link_set_2_270 | link_upper_tongue | 3.96 | 0.397 | 0.00 | thread 0.40 (M5 set screw forms its thread in the link's O4.2 hole) |
| link_set_2_270 | shaft_clamp_2 | 0.00 | 0.000 | 0.20 | gap 0.20 |
| link_set_2_90 | link_upper_tongue | 3.96 | 0.397 | 0.00 | thread 0.40 (M5 set screw forms its thread in the link's O4.2 hole) |
| link_set_2_90 | shaft_clamp_2 | 0.00 | 0.000 | 0.20 | gap 0.20 |
| link_upper_groove | link_upper_tongue | 0.00 | 0.000 | 0.00 | contact |
| link_upper_groove | shaft_clamp_1 | 0.00 | 0.000 | 0.02 | gap 0.02 |
| link_upper_groove | shaft_clamp_2 | 0.00 | 0.000 | 0.74 | gap 0.74 |
| link_upper_tongue | shaft_clamp_1 | 0.00 | 0.000 | 0.50 | gap 0.50 |
| link_upper_tongue | shaft_clamp_2 | 0.00 | 0.000 | 0.02 | gap 0.02 |
| shaft_clamp_1 | shaft_clamp_2 | 0.00 | 0.000 | 1.00 | gap 1.00 |

## J3 elbow  (cut: point (np.float64(0.0), np.float64(0.0), np.float64(0.0)), normal (np.float64(1.0), np.float64(0.0), np.float64(0.0)); 30 parts in the cut)

| part A | part B | overlap mm2 | overlap thickness | gap | verdict |
|---|---|---|---|---|---|
| J3_p1 | J3_p2 | 0.00 | 0.000 | 0.00 | contact |
| J3_p1 | J3_shaft | 0.00 | 0.000 | 0.54 | gap 0.54 |
| J3_p1 | brg_J3_drive | 0.00 | 0.000 | 0.00 | contact |
| J3_p1 | brg_J3_idle | 0.00 | 0.000 | 0.00 | contact |
| J3_p1 | ear_bolt_fore | 0.00 | 0.000 | 1.20 | gap 1.20 |
| J3_p1 | link_fore_groove | 0.00 | 0.000 | 1.00 | gap 1.00 |
| J3_p1 | link_fore_tongue | 0.00 | 0.000 | 1.00 | gap 1.00 |
| J3_p1 | link_upper_tongue | 0.00 | 0.000 | 0.00 | contact |
| J3_p1 | pin_J3_fork_+1 | 0.00 | 0.000 | 0.55 | gap 0.55 |
| J3_p1 | pin_J3_fork_+1_ins | 0.00 | 0.000 | 0.00 | contact |
| J3_p1 | pin_J3_fork_-1 | 0.00 | 0.000 | 0.55 | gap 0.55 |
| J3_p1 | pin_J3_fork_-1_ins | 0.00 | 0.000 | 0.00 | contact |
| J3_p1 | servo_J3 | 0.00 | 0.000 | 0.00 | contact |
| J3_p1 | shaft_clamp_3 | 0.00 | 0.000 | 1.00 | gap 1.00 |
| J3_p1 | spring_J3_+1 | 0.00 | 0.000 | 1.51 | gap 1.51 |
| J3_p1 | spring_J3_-1 | 0.00 | 0.000 | 1.51 | gap 1.51 |
| J3_p2 | servo_J3 | 0.00 | 0.000 | 0.40 | gap 0.40 |
| J3_shaft | brg_J3_drive | 0.00 | 0.000 | 0.02 | gap 0.02 |
| J3_shaft | brg_J3_idle | 0.00 | 0.000 | 0.02 | gap 0.02 |
| J3_shaft | horn_screw_J3_0 | 0.00 | 0.000 | 0.00 | contact |
| J3_shaft | horn_screw_J3_180 | 0.00 | 0.000 | 0.00 | contact |
| J3_shaft | link_fore_groove | 0.00 | 0.000 | 1.02 | gap 1.02 |
| J3_shaft | link_fore_tongue | 0.00 | 0.000 | 1.02 | gap 1.02 |
| J3_shaft | servo_J3 | 0.00 | 0.000 | 0.00 | contact |
| J3_shaft | shaft_clamp_3 | 0.23 | 0.016 | 0.00 | fit/seat 0.016 |
| J3_shaft | shaft_clamp_4 | 0.23 | 0.016 | 0.00 | fit/seat 0.016 |
| collar_upper_+y | link_upper_tongue | 0.00 | 0.000 | 0.20 | gap 0.20 |
| collar_upper_+y | pin_J2_collar_+1 | 0.00 | 0.000 | 0.30 | gap 0.30 |
| collar_upper_+y | pin_J2_collar_+1_ins | 0.00 | 0.000 | 0.00 | contact |
| collar_upper_+y | spring_J2_+1 | 0.00 | 0.000 | 1.51 | gap 1.51 |
| collar_upper_-y | link_upper_groove | 0.00 | 0.000 | 0.20 | gap 0.20 |
| collar_upper_-y | pin_J2_collar_-1 | 0.00 | 0.000 | 0.30 | gap 0.30 |
| collar_upper_-y | pin_J2_collar_-1_ins | 0.00 | 0.000 | 0.00 | contact |
| collar_upper_-y | spring_J2_-1 | 0.00 | 0.000 | 1.51 | gap 1.51 |
| ear_bolt_fore | ear_ins_fore | 0.00 | 0.000 | 0.00 | contact |
| ear_bolt_fore | link_fore_groove | 0.00 | 0.000 | 0.50 | gap 0.50 |
| ear_bolt_fore | link_fore_tongue | 0.00 | 0.000 | 0.00 | contact |
| ear_ins_fore | link_fore_groove | 0.00 | 0.000 | 0.00 | contact |
| ear_ins_fore | link_fore_tongue | 0.00 | 0.000 | 0.00 | contact |
| horn_screw_J3_0 | servo_J3 | 0.00 | 0.000 | 0.00 | contact |
| horn_screw_J3_180 | servo_J3 | 0.00 | 0.000 | 0.00 | contact |
| link_fore_groove | link_fore_tongue | 0.00 | 0.000 | 0.00 | contact |
| link_fore_groove | shaft_clamp_3 | 0.00 | 0.000 | 0.08 | gap 0.08 |
| link_fore_groove | shaft_clamp_4 | 0.00 | 0.000 | 0.77 | gap 0.77 |
| link_fore_tongue | shaft_clamp_3 | 0.00 | 0.000 | 0.51 | gap 0.51 |
| link_fore_tongue | shaft_clamp_4 | 0.00 | 0.000 | 0.08 | gap 0.08 |
| link_upper_groove | link_upper_tongue | 0.00 | 0.000 | 0.00 | contact |
| pin_J2_collar_+1 | pin_J2_collar_+1_ins | 0.00 | 0.000 | 0.00 | contact |
| pin_J2_collar_+1 | spring_J2_+1 | 0.00 | 0.000 | 0.00 | contact |
| pin_J2_collar_-1 | pin_J2_collar_-1_ins | 0.00 | 0.000 | 0.00 | contact |
| pin_J2_collar_-1 | spring_J2_-1 | 0.00 | 0.000 | 0.00 | contact |
| pin_J3_fork_+1 | pin_J3_fork_+1_ins | 0.00 | 0.000 | 0.00 | contact |
| pin_J3_fork_+1 | spring_J3_+1 | 0.00 | 0.000 | 0.00 | contact |
| pin_J3_fork_-1 | pin_J3_fork_-1_ins | 0.00 | 0.000 | 0.00 | contact |
| pin_J3_fork_-1 | spring_J3_-1 | 0.00 | 0.000 | 0.00 | contact |
| shaft_clamp_3 | shaft_clamp_4 | 0.00 | 0.000 | 1.00 | gap 1.00 |

## J4 forearm roll  (cut: point (np.float64(0.0), np.float64(0.0), np.float64(0.0)), normal (np.float64(0.0), np.float64(1.0), np.float64(0.0)); 10 parts in the cut)

| part A | part B | overlap mm2 | overlap thickness | gap | verdict |
|---|---|---|---|---|---|
| J5_p1 | j4_hub | 0.00 | 0.000 | 0.00 | contact |
| brg_J4 | j4_cap | 0.00 | 0.000 | 0.00 | contact |
| brg_J4 | j4_hub | 0.00 | 0.000 | 0.00 | contact |
| horn_screw_J4_0 | j4_hub | 0.00 | 0.000 | 0.00 | contact |
| horn_screw_J4_0 | servo_J4 | 0.00 | 0.000 | 0.00 | contact |
| horn_screw_J4_180 | j4_hub | 0.00 | 0.000 | 0.00 | contact |
| horn_screw_J4_180 | servo_J4 | 0.00 | 0.000 | 0.00 | contact |
| j4_base | link_fore_tongue | 0.00 | 0.000 | 0.00 | contact |
| j4_base | servo_J4 | 0.00 | 0.000 | 0.00 | contact |
| j4_cap | j4_hub | 0.00 | 0.000 | 0.50 | gap 0.50 |
| j4_hub | servo_J4 | 0.00 | 0.000 | 0.00 | contact |

## J5 wrist pitch  (cut: point (np.float64(0.0), np.float64(0.0), np.float64(0.0)), normal (np.float64(1.0), np.float64(0.0), np.float64(0.0)); 13 parts in the cut)

| part A | part B | overlap mm2 | overlap thickness | gap | verdict |
|---|---|---|---|---|---|
| J5_p1 | J5_p2 | 0.00 | 0.000 | 0.00 | contact |
| J5_p1 | J5_shaft | 0.00 | 0.000 | 0.54 | gap 0.54 |
| J5_p1 | J5_spacer_B | 0.00 | 0.000 | 0.50 | gap 0.50 |
| J5_p1 | brg_J5_drive | 0.00 | 0.000 | 0.00 | contact |
| J5_p1 | brg_J5_idle | 0.00 | 0.000 | 0.00 | contact |
| J5_p1 | j4_hub | 0.00 | 0.000 | 0.00 | contact |
| J5_p1 | j6_body | 0.00 | 0.000 | 1.00 | gap 1.00 |
| J5_p1 | servo_J5 | 0.00 | 0.000 | 0.00 | contact |
| J5_p2 | servo_J5 | 0.00 | 0.000 | 0.40 | gap 0.40 |
| J5_shaft | J5_spacer_A | 0.00 | 0.000 | 0.12 | gap 0.12 |
| J5_shaft | J5_spacer_B | 0.00 | 0.000 | 0.12 | gap 0.12 |
| J5_shaft | brg_J5_drive | 0.00 | 0.000 | 0.02 | gap 0.02 |
| J5_shaft | brg_J5_idle | 0.00 | 0.000 | 0.02 | gap 0.02 |
| J5_shaft | horn_screw_J5_0 | 0.00 | 0.000 | 0.00 | contact |
| J5_shaft | horn_screw_J5_180 | 0.00 | 0.000 | 0.00 | contact |
| J5_shaft | j6_body | 0.00 | 0.000 | 0.09 | gap 0.09 |
| J5_shaft | servo_J5 | 0.00 | 0.000 | 0.00 | contact |
| J5_spacer_A | brg_J5_drive | 0.00 | 0.000 | 0.00 | contact |
| J5_spacer_A | j6_body | 0.00 | 0.000 | 0.00 | contact |
| J5_spacer_B | brg_J5_idle | 0.00 | 0.000 | 0.00 | contact |
| J5_spacer_B | j6_body | 0.00 | 0.000 | 0.00 | contact |
| horn_screw_J5_0 | servo_J5 | 0.00 | 0.000 | 0.00 | contact |
| horn_screw_J5_180 | servo_J5 | 0.00 | 0.000 | 0.00 | contact |
| j6_body | servo_J6 | 6.42 | 0.110 | 0.00 | fit/seat 0.110 |

## J6 tool roll  (cut: point (np.float64(0.0), np.float64(0.0), np.float64(0.0)), normal (np.float64(0.0), np.float64(1.0), np.float64(0.0)); 9 parts in the cut)

| part A | part B | overlap mm2 | overlap thickness | gap | verdict |
|---|---|---|---|---|---|
| J5_shaft | j6_body | 0.00 | 0.000 | 0.05 | gap 0.05 |
| brg_J6 | j6_cap | 0.00 | 0.000 | 0.00 | contact |
| brg_J6 | j6_flange | 0.00 | 0.000 | 0.00 | contact |
| horn_screw_J6_0 | j6_flange | 0.00 | 0.000 | 0.00 | contact |
| horn_screw_J6_0 | servo_J6 | 0.00 | 0.000 | 0.00 | contact |
| horn_screw_J6_180 | j6_flange | 0.00 | 0.000 | 0.00 | contact |
| horn_screw_J6_180 | servo_J6 | 0.00 | 0.000 | 0.00 | contact |
| j6_body | servo_J6 | 0.00 | 0.000 | 0.00 | contact |
| j6_cap | j6_flange | 0.00 | 0.000 | 0.50 | gap 0.50 |
| j6_flange | servo_J6 | 0.00 | 0.000 | 0.00 | contact |

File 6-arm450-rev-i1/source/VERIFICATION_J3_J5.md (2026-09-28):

# J3 / J5 fork regeneration — verification record

Date: 2026-09-23. Parts: `J3_p1`, `J3_p2`, `J5_p1`, `J5_p2`, plus a
re-fixed `J4_module`. Every number below is measured from the generated
solids or the user's own servo mesh — none is copied from a parameter file.

## The two defects fixed

**1. No servo bay at all.** The released `J3_p1` / `J5_p1` end at the
parting plane (z = 28.50 for J3), so the drive cheek — and with it the
entire servo cradle — was never built. `fork_pro.fork()` does construct
one; the released parts came from a different path. Regenerating through
`fork_p1` / `fork_p2` restores it.

**2. `BAY_W` and `BAY_T` were swapped.** `fork_pro` cuts the bay as
`rect(BAY_L, BAY_W)` extruded `BAY_T` along **+Z**, and +Z *is* the joint
axis (every bearing bore is a `circle()` on XY). So `BAY_T` is the
dimension along the servo's **output axis**.

Measured from the user's `Motor.stl` (re-derived and self-checked by
`servo_geom.py`):

| along the output axis | mm |
|---|---|
| mounting face → back of cable boss | 33.10 |
| mounting face → face of horn disc | 4.50 (opposite way) |

Case cross-section normal to the output axis: **45.22 × 24.72**.

`fixparams` derived `BAY_W = 38.05` where 24.72 is needed (**13.33 mm of
slop** — the servo could rattle and rotate) and `BAY_T = 26.62` where 33.50
is needed (**6.88 mm too shallow** — it would not go in).

## Orientation lock: pinch + strap

The four front-face case screws **cannot** be used on these joints. The
real pattern is 19.05 × 20.29, giving a bolt-circle radius of **13.92 mm**,
which falls inside the **Ø38 bearing seat (r 19.00)**. That seat carries
the outer race and cannot be shrunk. The back face cannot be bolted either:
the photographs show the two JST bus connectors and the rear bearing boss
occupying its centre.

So the lock is the user's own proven arrangement from `motor fixer.stl`: a
**24.50 mm channel on the 24.72 mm case face = −0.22 mm interference**,
plus a strap on the two M3 inserts. Measured back out of the solid, the
channel is **24.500 mm at every station on both joints**.

## Results

| check | J3 | J5 |
|---|---|---|
| single solid, both halves | yes | yes |
| horn offset from joint axis | **0.0000 mm** | **0.0000 mm** |
| servo inside bay depth | yes (z 23.99–61.59 in 28.50–62.00) | yes (z 20.99–58.59 in 25.50–59.00) |
| horn passes through floor into bore | yes | yes |
| pinch penetration | 0.112 mm/side | 0.112 mm/side |
| contact **off** the pinch faces | **0 points** | **0 points** |
| p1/p2 interpenetration | **0 / 20000 both ways** | **0 / 20000 both ways** |
| parting-plane gap | 0.0000 mm (adjacent) | 0.0000 mm |
| 4 joint bolts clear through p2 | 4/4 | 4/4 |
| 8 inserts enclosed in solid | 12/12 probes each | 12/12 each |
| strap-bolt driver run (6 mm) | >60 mm clear | >60 mm clear |
| layer-slice findings | **0** | **0** |
| thin-feature findings | **0** | **0** |

### Seating-test controls
The test reads clean at nominal and detects real clashes:
`+6 mm into the back wall` → 917 off-pinch points; `−14 mm into the −X
wall` → 748. Nominal → **0**.

### Rotational play — an honest limitation
Rotating the servo about the joint axis produces no off-pinch contact up to
**≈2°**. The pinch alone therefore permits a couple of degrees of play;
**the strap is what closes it**, exactly as on the arm the user has already
built. The strap is not optional on these joints.

## Two gate bugs found and fixed

Both gates paired parallel planes on offset alone, ignoring which way each
face points and whether the footprints overlap. That manufactured findings
on solid material.

* `slice_check.z_thin_bands` — now requires the lower plane to face **down**
  and the upper to face **up**, with ≥1 mm² of real (grid, not convex-hull)
  overlap. An annulus hull fills its own hole and invents an overlap.
* `check_thin.planes` — now carries the outward sense and the face bounding
  box; pairs must be opposed and overlap.

**Validation held**: both still flag the known-bad released `J4_module`
(0.020 mm and 0.100 mm membranes) and both still pass the known-good
`base`. False findings disproved by direct probing: `J5_p1` "0.100 mm"
(270 probe columns, **0** isolated sub-layer runs) and `J4` "0.375 mm"
(two separate walls at different x).

## J4_module — a real defect found and fixed

The blind J5-fork inserts bottomed at `36.72 − 7.50 = 29.220` while a bore
ceiling beside them sat at 29.200, leaving a **0.0198 mm disc of material,
7.75 mm²** — a tenth of a layer. The printer steps over it, leaves a hole,
and the insert bottoms on nothing. Insert depth 7.50 → **8.00** puts the
floor at 28.720, clear by 0.48 mm (>2 layers). `J4_module` now returns
**0 findings** on both gates.

## Consequence to carry forward

`z_drive` moves **out by 6.88 mm** on both joints (J3 57.52 → 64.40, J5
54.52 → 61.40). Downstream link face positions depend on this and have
**not** yet been re-derived.

## What is NOT verified (and why no blanket GO)

**`check_access.py` reads `ARM450_FINAL_ASSEMBLY.step`, dated 11 Sep** —
twelve days older than these parts, and built before the forks had a servo
bay at all. Its 14 "no room for a hex key" stations describe superseded
geometry; several are at (0,0,0), i.e. parts never placed. **That run tells
us nothing about the current parts and must not be quoted as a result.**

Bolt access for J3/J5 was therefore checked directly on the new solids
(strap bolts >60 mm clear, 4/4 joint bolts clear through p2, 8/8 inserts
enclosed). That covers J3 and J5. It does **not** cover the arm as a whole.

Still open, all requiring a rebuilt assembly:

1. **Whole-arm bolt access and assembly order** — must be re-run once the
   assembly is rebuilt with these parts at their true positions.
2. **Joint motion through full travel** — swing clearance with the 6.88 mm
   longer cheeks has not been simulated.
3. **Wiring clearance** — the servo cable exit is in the back wall; no
   routing check has been done.
4. **J2** — `j2_clamp` was never attempted. J2 mounts on the turret shell
   at y = −28.50 with 6 × Ø4.1 stations.
5. **Downstream link faces** — `z_drive` moved out 6.88 mm on both joints.
   The mounting face, bearing seats, spigot and end-bolt pattern are all
   confirmed unmoved, so the change is contained to cheek length, but the
   links that sit beyond it have not been re-derived.

## Print status

**Not a full GO.** J3_p1, J3_p2, J5_p1, J5_p2 and J4_module are clean on
every check that has actually been run against them, and the servo seats
correctly with its shaft on the joint axis to 0.0000 mm. But items 1–5
above are unverified, and item 5 in particular can move real material.
Printing the five parts now risks a reprint if a link face has to change.

---

# UPDATE — J5 is a different part, and it does not work

## Retraction

The first pass of `gen_forks.py` generated **J5 with J3's recipe**. That was
wrong. `wrist_pro.py` builds J5 from the same `fork_pro.fork_p1/p2` but adds
two load-bearing steps I had omitted:

* **`mirror=True`** — puts the drive cheek on the far side of the blade from
  the tool. Built the other way it grows along +Z and swallows the J6
  bearing and the tool flange.
* **`_clip_j5()`** — cuts the cheeks back to `J5_CLIP = 11.0` past the bore.
  Unclipped they overhang the J6 axis ~30 mm and run through the Ø40 flange.

My J5 was neither mirrored nor clipped: local x −44.00..37.90 against the
released −25.28..11.00. It was **not** a drop-in replacement and the earlier
J5 numbers in this document describe a part that cannot be used. The J3
numbers are unaffected — J3's transform and recipe were correct.

## The real J5 defect

With the correct recipe the servo does not fit, and **this is true of the
released part as well as mine**:

| along the fork's local x | mm |
|---|---|
| mounting face (`J5_FACE`, fixed by J4→J5 link spacing) | −25.28 |
| clip plane (`J5_CLIP`, fixed by the J6 bearing and Ø40 flange) | +11.00 |
| **usable** | **36.28** |
| ST3215 case needs (`45.22 + 2×0.40`) | **46.02** |
| **short by** | **9.74** |

`BAY_L` was already 46.02 before my change, so this shortfall is not
something the bay correction introduced.

**Measured on the released `out_cad/J5_p2.stl`**, not inferred: a material
map at z = −30, −40, −50 shows an open C-channel — a back plate with two
short flanges. Probing along x at y = 0 returns **no material anywhere**;
probing along y at x = −5 returns only `−24.99..−22.61`, `−21.42..−19.03`,
`19.03..21.42`, `22.61..24.99`. Two thin flange pairs with nothing between
them.

**The released J5_p2 cannot hold a servo.** It is open on the +x side and
has no floor. This is the same class of defect as the missing J3 bay, and it
was in the shipped package.

## Consequence

J5 cannot be fixed by regenerating with corrected bay numbers. The servo is
9.74 mm too long for the space between a mounting face fixed by link spacing
and a clip plane fixed by the tool flange. Resolving it needs a design
decision — move the J4→J5 spacing, shrink the tool flange, or drive J5
off-axis through a belt/gear — and that is beyond a parameter change.

**J5_p1 / J5_p2 are withdrawn from this print.** The earlier "0 findings"
gate results for them were run on the wrongly-generated part and do not
carry over.

---

# FINAL STATE — 2026-09-23

## Generated and verified

`gen_forks.py` now builds **J3 only**. J5 is withdrawn with the reason
recorded in the source itself, so it cannot be silently regenerated.

Re-run after the withdrawal, J3 is unchanged from the numbers above:
horn offset **0.0000 mm**, pinch **0.112 mm/side**, **0 contact points off
the pinch faces**, controls detecting (+6 back wall → 1096, −14 −X wall →
805) against a clean nominal.

## Both gates, final set

| part | slice | thin |
|---|---|---|
| J3_p1 | 0 | 1.00 mm wall (see below) |
| J3_p2 | 0 | 0 |
| J4_module | 0 | 0 |
| j1_clamp, j1_drive_hub, j1_pod | 0 | 1.10 mm wall on drive_hub |
| j3_clamp, j5_clamp | 0 | 0 |
| servo_strap_micro, spigot_collar | 0 | 0 |

The two sub-1.20 mm walls are **not** sub-layer features. `J3_p1`'s
"O50.00/O52.00" was probed directly: where material exists the wall is
4–10 mm thick, so the pair is a geometric artifact, not a real thin wall.
`j1_drive_hub`'s 1.10 mm is 2.75 extrusions at a 0.40 nozzle — printable.

## Print recommendation

**GO for these ten parts**, with one caveat stated plainly:

* J3_p1, J3_p2, J4_module, j1_clamp, j1_drive_hub, j1_pod, j3_clamp,
  j5_clamp, servo_strap_micro, spigot_collar.
* The **strap is not optional** on J3 — the pinch alone leaves ~2° of
  rotational play and the strap is what removes it.

**NO-GO: J5_p1, J5_p2.** The ST3215 is 9.74 mm too long for the space
between the J5 mounting face and the clip plane. This is a design decision
(J4→J5 spacing, tool-flange diameter, or an off-axis drive), not a
parameter change. The released J5 has the same problem plus an open
C-channel with no floor.

## Still not verified

Whole-arm bolt access and joint motion could not be re-run: the only
assembly in the package is dated 11 Sep, and rebuilding it is blocked on
the J5 decision, since J5 sits between J4 and the tool. `j2_clamp` remains
unattempted.

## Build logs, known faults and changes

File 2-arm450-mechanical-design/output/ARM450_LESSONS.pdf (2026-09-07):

# ARM-450 — Mistakes, Corrections and Lessons

- Date: 2026-08-14
- Purpose: an honest record of every error found in this project — in the original design, and in my own analysis of it — with the reasoning that exposed each one.
- Why this document exists: you asked for it explicitly. Most of these are not careless slips; they are the standard traps of small-robot design, and each one is worth more as a rule than as a fix.

## Part I — Design errors found in the printed arm

M1. The servo mounts were sized for the wrong load — the one that actually broke
What happened: the motor mounts snapped during trials.
The error: they were sized for the 2.08 N·m the arm actually carries. A servo can deliver its stall torque — 2.94 N·m (ST3215), 4.90 N·m (ST3250) — into its own mount during a collision, a commanded step, or when it hits a joint limit.
The numbers: the 4 mm bracket runs at 17–95 MPa depending on where it grips, against a realistically sustainable ~9 MPa for printed PLA under repeated load. It fails under every assumption in that range.

RULE — whenever an actuator can drive its own structure to failure, the actuator's limit IS the design load. Gravity torque tells you what the servo must do. Stall torque tells you what the mount must survive.
The trap inside the trap: upgrading the shoulder to an ST3250 multiplies mount stress 2.36× while changing the load the arm actually carries by nothing at all.

M2. A thrust bearing was used where a moment-carrying bearing was needed — the largest error in the arm
What happened: visible gaps at the joints, wobble, and small oscillations that never settle.
The error: a Ø42 × 3.7 thrust ball bearing carries axial load only — balls run between two flat races, so the joint is free to tilt. But a robot joint's dominant load is a bending moment: 2.08 N·m at the shoulder from everything outboard on a long lever.
The numbers: angular play θ = 2c/d. With effectively no bearing spacing (d ≈ 5 mm) and 0.2 mm clearance, that is 28.9 mm of wobble at 360 mm reach — larger than every other error source in the arm combined.

RULE — match the bearing to the load direction, not to the shaft diameter. Radial and moment loads need deep-groove pairs, crossed-roller, or four-point-contact bearings. Thrust bearings take thrust.

ARM-450 — Mistakes, Corrections and Lessons · page 1

RULE — moment stiffness scales with bearing spacing SQUARED. Spacing is worth far more than bearing size or count.

M3. The oscillation was mechanical, not a tuning problem
The error: clearance in a position-controlled joint is a dead zone — the servo turns and nothing moves until the slack takes up, then it moves suddenly. A feedback controller pushing against a dead zone produces a limit cycle.

RULE — a limit cycle from backlash cannot be tuned out. Lowering gain makes the arm sluggish and the oscillation smaller, never absent. The fix is mechanical preload.

M4. The 1.1 revision lengthened only one link
The error: link1_base_1.1 grew to 195.1 mm joint-to-joint while link2_base stayed at 97.9 mm.
The numbers: the reachable region of a two-link chain is an annulus whose inner radius is |L2 − L3|. That split creates a Ø194 mm dead zone directly in front of the robot, and totals 453 mm — over the 450 mm limit.
What makes this sting: the original links were 97.9/97.9 — perfectly equal, zero dead zone. The revision broke something that was already right.

RULE — for a 2-link arm, L2 = L3 eliminates the workspace dead zone, and the cost is almost nothing. The optimisation study (§ below) shows shoulder torque is nearly flat in the split, because the dominant term is the payload at a fixed reach. Equal links are free.

M5. 450 / 6 — dividing the length budget evenly across all six segments
The error: an early sketch worked toward six equal 75 mm segments. That spends length on things that buy no reach (base height, wrist stack, tool) and starves the two links that do — roughly 225 mm of reach from a 450 mm arm.

RULE — the division that should be equal is L2 vs L3, not all six segments.

M6. Sharp internal corners in loaded brackets
Every reentrant corner is a crack starter. A printed "sharp" corner still has the nozzle radius (~0.2 mm), which at t = 4 mm is r/t = 0.05 → Kt ≈ 2.6. A 2 mm fillet gives r/t = 0.50 → Kt ≈ 1.3.

RULE — every internal corner in a load path gets r ≥ 0.5 t, minimum 2.0 mm. It costs nothing in mass or print time and cuts peak stress ~2.3×.

M7. An open (notched) section carrying torque
The U-channel motor fixer has a notch cut through it. Open sections are catastrophically poor in torsion: J ≈ 1,730 mm⁴ open vs ≈ 189,500 mm⁴ closed — 110×.

RULE — closing a section is the cheapest stiffness available anywhere in mechanical design.

A bridging strap or bolted cap is usually enough.

M8. Mismatched shell pair
link1_cover (envelope 196.5 mm) did not pair with link1_base (147.5 mm), while link2_cover (146.5) paired correctly with link2_base (147.5) — a leftover from an intermediate revision. You have since fixed this in the new assembly.

RULE — when a clamshell exists in several generations, check that base and cover come from the same one. It is also a strong candidate cause of URDF export failures.

M9. An unconstrained body left floating in the assembly
Found: 2026-08-14, in the rebuilt robotic_arm_assembly.stl.
The base-to-arm mismatch was genuinely fixed — those two groups now mate with zero gap. But one yoke-class component sits 429 mm away in Y, unconstrained. It alone inflates the assembly envelope from ~440 mm to 659 mm.

RULE — check an assembly's bounding box against the design intent before exporting. An envelope 50 % larger than the arm's own length is a free, instant signal that something is unmated. It costs one measurement and catches exactly this class of error.
This is also a strong candidate for the URDF export failures: an exporter walking the assembly tree hits a body with no mate and either drops it or emits a disconnected link.

## Part II — Errors in my analysis

These were found by adversarial review and then verified independently. Rev 1 of the analysis report had already been issued when they were caught.

A1. I bent the link about the wrong axis — the significant one
What I did: computed I about the 29.0 mm dimension → I = 39,899 mm⁴.
Why it was wrong: the ST3215 is 24.7 mm thick and the link's split-normal cavity is 29.0 − 2(2.0) = 25.0 mm — a deliberate 0.3 mm clearance fit. The servo output axis is normal to its 45.2 × 37.8 face, so the joint axis lies along the 29.0 mm direction. That axis is horizontal, therefore 47.5 mm is the vertical bending depth.
Correct value: I = 87,514 mm⁴. Every droop figure in rev 1 was 2.19× too pessimistic.

LESSON — the servo's own fit inside the shell told me the bending orientation, and I did not look. When a part's dimensions include a 0.3 mm clearance on a 25 mm cavity, that is not a coincidence, it is the designer telling you how the part is used.

A2. I claimed an open-section bending penalty that does not exist What I did: stated an unbolted seam costs 4× in bending, by applying a stacked-section rule.
Why it was wrong: the split plane is parallel to the bending plane, so the two half-shells sit side by side about the same neutral axis and their second moments simply add.

I_open = I_closed. There is no bending penalty at all.
And the correction cut the other way too: the torsion penalty is 215×, not the 126× I reported, because my open_J had double-counted the section width.

LESSON — where a section is split relative to the load matters more than that it is split. The seam sits at the extreme fibres, where bending shear flow is zero. It carries essentially only torsional shear flow.

A3. I omitted J1 from the backlash budget
Three joints swing the tool, not two. Corrected RSS at 0.5°: 4.82 mm, not 3.66 mm.

A4. I used the wrong lever arm for shell twist
A twist about the link's longitudinal axis swings the tool by its perpendicular offset from that axis — not by the wrist length.

A5. I modelled the two links as separate cantilevers
That understates the moment arm roughly 3×. The correct model is one continuous cantilever of length a = L2 + L3 = 290 mm with a rigid overhang b = 70 mm. (Caught and fixed before rev 1 was issued.)

A6. I specified a bearing fit from a generic assumption instead of asking for a measurement
What I did: specified a pocket at Ø42.15, based on the usual FDM 0.1–0.4 mm hole undersize.
Why it was wrong: your printer measures 0.02 mm undersize in XY — very well calibrated. My pocket would have left 0.13 mm of clearance → 1.17 mm of wobble, not the 0.36 mm I promised. It would have quietly defeated the entire bearing redesign. Corrected: model the pocket at Ø42.00, so the 0.02 mm shrinkage itself becomes a light 0.02 mm interference press fit.

LESSON — a fit is not a number you can look up; it is a property of a specific machine. The generic value was not merely imprecise, it inverted the outcome. Measure first.

AND — shrinkage is anisotropic. Yours is 0.02 mm in XY and negligible in Z. That is exactly why a bearing bore must print with its axis vertical: the bore is then a circle in the XY plane and shrinks uniformly. Printed on its side it would shrink in XY but not Z and come out oval — reintroducing the very tilt the redesign exists to remove.

A7. I put a cantilever stub arm on the servo collar
My first collar had a stub arm to reach the link — the exact bending topology my own report condemns in M1. Replaced with a bolt flange that sits flat against the shell, putting the fasteners in shear with no bending arm.

LESSON — writing the rule down does not stop you breaking it while modelling.

A8. A degenerate demo case hid a real result
My roll-joint demo applied the tool offset along an axis that happened to point straight down, so the moment computed as exactly zero and appeared to prove roll joints are never loaded. The offset must be perpendicular to both the roll axis and gravity.

LESSON — a result of exactly zero deserves suspicion, not satisfaction.

A9. I built the capsule profile with a non-tangent end boss
Found: 2026-08-17, by the user, on the very first printed pair — visible misalignment of the seam exactly where the straight section meets the end boss. They asked whether it was printer shrinkage. It was not; it was my geometry.
The error: I built the capsule as a rectangle of half-height 23.75 mm unioned with end circles of radius 25 mm. Those are not equal, so the boss circle bulges past the rectangle edge instead of being tangent to it. The two curves meet at a sharp vertex at x = 7.81 mm, at a shallow 18.2° included angle.
Why a shallow vertex is dangerous: an offset applied to a face moves that face by the offset. An offset applied at a vertex moves the intersection point by offset / sin(angle). At 18.2°:

0.15 mm tongue/groove clearance -> 0.15 / sin(18.2°) = 0.48 mm along the profile
So a clearance I chose as 0.15 mm became ~0.5 mm of positional mismatch at that one corner — visible to the eye, and exactly where the user saw it.
Ruling out shrinkage: their measured 0.02 mm shrink, amplified identically, gives 0.064 mm — 8× smaller than the geometric error and far too small to see.
The fix: make it a true stadium by setting SEC_H/2 = BOSS_R = 25, so the arc is tangent to the edge and there is no vertex at all. BOSS_R could not be reduced — a Ø42 bearing needs ≥ 21 + 2.4 mm of wall — so the section rose from 47.5 to 50.0 mm deep. Bonus: I improved from 101,992 to 115,853 mm⁴, 13.6 % stiffer.

LESSON — offsets amplify at shallow-angle vertices, by 1/sin(θ). Wherever two surfaces meet at a shallow angle, any clearance, tolerance or offset you apply is multiplied there. The cure is to remove the vertex, not to tighten the tolerance.

LESSON — a "capsule" built as rectangle ∪ circles is only a stadium if the half-height equals the radius. Otherwise it is a rectangle with two bulges and a kink at each junction.

## Part III — The rules, collected

# | Rule

1 | An actuator's stall torque is the design load for everything it can drive to failure.
2 | Match the bearing to the load direction. Thrust bearings take thrust, not moment.

# | Rule

3 | Moment stiffness scales with bearing spacing squared.
4 | Backlash limit cycles cannot be tuned out. Preload is mechanical.
5 | For a 2-link arm, L2 = L3 removes the workspace dead zone and costs almost nothing.
6 | Internal corners in a load path: r ≥ 0.5 t, minimum 2 mm.
7 | Closing an open section is the cheapest stiffness in mechanics — up to 215× in torsion.
8 | Fits are properties of your machine. Measure a coupon; never assume.
9 | Shrinkage is anisotropic — orient critical bores so the accurate axis defines them.
10 | In bending, the outer quarter of the depth carries ~87 % of the moment: perimeters beat infill.
11 | A result of exactly zero deserves suspicion.
12 | Where a section is split matters more than that it is split.
13 | Check the assembly bounding box against design intent before exporting — an oversized envelope means something is unmated.
14 | Offsets amplify at shallow-angle vertices by 1/sin(θ). Remove the vertex, don't tighten the tolerance.
15 | A capsule is only a true stadium when half-height = end radius; otherwise it has a kink at each junction.

## Part IV — What was never wrong

Worth stating, because the effort should go where it pays:
- The link shells. Peak stress 0.15 MPa against a ~9 MPa derated allowable — a safety factor around 60. They were never the problem, and the topology optimisation independently confirms the box section is the right shape.
- The capsule clamshell construction. A split shell prints support-free with a flat mating face, and the split plane is parallel to the bending plane so it costs nothing in bending stiffness.
- The original 97.9/97.9 equal links. Correct, and undone by a later revision.

- The general proportions and design language. The arm looks like a robot arm and nothing like a myCobot, which was the original brief.

## A per-unit number that is never multiplied out

2026-08-20 — the shaft mass. The purchasing list specified steel tube Ø30 × 5 mm wall and, two lines later, described it as "~93 g". Those two statements cannot both be true: that tube is 222 g at 72 mm. Meanwhile the pre-print mass gate carried the line 2 * 93 — it counted two shafts when the arm has twelve bearings, which is six pairs, which is six joints, which is six shafts.
The two errors concealed each other. The gate reported 1144 g and passed, because it was weighing an arm with two shafts in it. The true figure with the specified steel was 2270 g — nearly double the 1.2 kg requirement, and the single largest constraint violation in the project.
Neither error was a modelling mistake. Every individual analysis was right; the shaft was simply never multiplied by its own quantity, and the spec and the mass estimate were written at different times without either being checked against the other.
What caught it: the user asking "won't that make it heavy?" — arithmetic anyone can do in their head, applied to a number I had computed precisely and then never sanity-checked.
What it changed: aluminium Ø30 × 2 mm wall is now the spec (34 g each, 205 g for six, 1144 g total — the only option of five that closes the budget). The gate derives the shaft mass and count from params.py instead of hard-coding it, and asserts N_SHAFT * 2 == 12 so the count can never silently disagree with the bearing count again.
The wider lesson: a bill of materials has two columns, and analysis attention goes almost entirely to the left one. Quantity is where the cheap catastrophic errors live. Any per-unit mass, cost, or power figure should be written down already multiplied out.
A second finding, worth keeping for its own sake: printing the shaft was rejected early on the assumption it would be too weak. Running the numbers showed the opposite — at servo stall a printed Ø30 shaft sees 0.55 MPa shear (SF 32) and 0.57 MPa bending (SF 104). It is nowhere near failing structurally. It fails for two local reasons: the M5 preload thread strips (cut across layer lines, ~18 MPa capacity against ~16 MPa demand), and the press fit creeps away because a press fit is stored elastic strain and plastic relaxes. Rejecting it for the right reason led to a better design — metal only at the thread and the bearing seats, which is what made the light tube viable.

## Grip length is not boss height

2026-08-21 — the seam screws. The purchasing list specified M3 × 12 for the link seams and M2.5 × 10 for the tip ears. Both are too short to work at all.
The seam screw enters from outside, through the flat back face of the tongue half, and threads into an insert in the groove half. Its grip is therefore the full half-shell depth, 14.50 mm — not the boss height, and not the wall thickness. An M3 × 12 stops 2.5 mm short of the seam plane; it never touches the insert. Correct is M3 × 20 (14.5 grip + 5.8 insert), and M2.5 × 18 for the ears.
There is a ceiling as well as a floor: the blind hole is 7.5 deep against a 5.8 insert, so a screw longer than 22.0 mm bottoms out and jacks the two halves apart — recreating precisely the seam gap that the tongue-and-groove was added to close.
Why it was missed: the fastener table was written by looking at the parts, and a 14.5 mm half-shell looks like a thin part. The screw does not pass through a thin wall, it passes through the whole depth of the shell. Nothing in the CAD flags this, because CadQuery models the hole, not the fastener that goes in it.
The user caught it by asking a simple question about the drawing — "does the external bolt placing come on top of it?" — which forced the fastener path to be traced end to end for the first time.
General rule: a fastener schedule should record grip length, measured through the assembly, alongside the part it fastens. A length quoted without a grip is a guess.

## Two tool interfaces in one machine that did not match

2026-08-21 — the missing Ø10 pilot. cad/base_wrist.py has defined the standard tool interface since the beginning: 4 × M3 on a Ø30 bolt circle, Ø10 centre pilot. When the wrist was integrated into three parts, wrist_j6_output() grew its own tool flange — and got the bolt circle but not the pilot. Two tool mounting faces in the same machine, specified the same way in prose, built differently in CAD.
Without the pilot a tool is located only by four clearance holes, so it can sit off-centre by the hole clearance — on a machine whose whole argument is about hundredths of a millimetre. The pilot also doubles as the cable route from the tool into the hollow wrist. Worse: the isometric drawing I had just produced called out "Ø10.00 PILOT" on a part that did not have one. A drawing asserting a feature that is absent is the most dangerous kind of drawing error, because it is trusted.
The user caught it by looking at the sheet and saying the part was missing something. Root cause, and the real fix: output/cad/volumes.json is the authority for part mass everywhere — the mass gate, the drawings, the URDF meshes, the BOM. Nothing regenerated it. Every script read it; none wrote it. It had been produced once by hand and went stale the moment any part changed, which is why the drawing kept quoting the pre-pilot mass, and why fit_coupon and shaft_tube were missing from it entirely. There is now a cad/volumes.py that rebuilds it from the STEP files and prints a diff of what moved.
General rule: any generated file that several tools read must have exactly one script that writes it, and that script must be runnable on demand. A derived file with no generator is a stale file waiting to happen.

## A correction factor applied to a model that was already corrected

2026-08-21 — the infill factor. The mass gate multiplied every part's exact STEP volume by 0.55 for sparse infill. That number is right for a part modelled solid and printed with sparse infill. Every part in this arm is modelled hollow — 2.4 mm link walls, a 3.0 mm base shell — so the STEP volume already is the wall material. Slicing a 2.4 mm wall with 4 perimeters on a 0.6 nozzle produces 2.4 mm of solid extrusion; there is no interior left for infill to save anything in.
The factor was discounting the hollowing a second time. It hid about 240 g: the gate reported 1215 g for an arm that weighs 1437 g.
Why it survived so long. It was applied uniformly, so every part looked consistent with every other part, and the total moved plausibly whenever geometry changed. A wrong factor applied everywhere produces a self-consistent table — nothing inside the numbers disagrees. It only surfaced because adding the 24 g horn adapter pushed the total past the limit and forced the model itself to be questioned rather than the parts. The tell that should have been caught earlier: the same 0.55 was applied to parts whose own drawings specify 100 % infill — the clamps, collars and adapters. A factor that contradicts the process sheet on the same page is wrong by inspection.
General rule: a correction factor needs its assumption written next to it. 0.55 means nothing; 0.55 — sparse infill, valid only for solid-modelled parts would have been checked against a hollow part the first time someone read it. FILL = 0.90 now carries that note.
Outcome. Offered a lightening pass (~1333 g) or narrower bearings (~1148 g), the user accepted 1437 g rather than thin the link walls — bending stiffness goes as thickness cubed, and that stiffness is what the whole bearing redesign exists to protect. 1450 g is now a hard ceiling: the gate fails on it rather than warning, with 13 g of headroom.
A second correction, in the same session: I quoted a bearing swap as saving "~90 g" without computing it. The real figures are 37 g for 6805 and 185 g for 6706 — wrong in both directions. An unverified number offered as a basis for a design decision is worse than no number, because it gets acted on.

## Checking the space instead of the path

2026-08-21 — the sine collision. interference.py samples the whole joint-limit box and reports about 30 % of poses colliding. That number had been on screen for days and was read as background: the box is enormous, most of it is nowhere the arm needs to go, and the sine task was known to work.
The task did not work. Running the same exact-mesh test on the 240 solved waypoints found 72 of them colliding — the upper arm grazing the top rim of the base pedestal by 1.27 mm. The demo that had been reported as verified would have ground plastic on 30 % of its stroke.
Two different questions. "Can the arm collide anywhere in its joint limits?" and "does this trajectory collide?" have almost nothing to do with each other. The first was being answered and quietly ignored; the second was never asked. A high number on an irrelevant test is worse than no test, because it trains you to ignore that class of result. The fix was strictly better in every dimension, which is itself worth noticing. Raising the trace 20 mm cleared every pose and improved accuracy 14× (0.194 → 0.014 mm rms).

Both came from the same cause: at the old height the IK was working hard against the J2 limit, and a solver pinned against a limit is both inaccurate and in an extreme posture. When a fix improves everything at once, the original setting was usually not a considered trade-off — it was an accident nobody had questioned.
Two attempted fixes that did not work, kept because knowing what fails is worth as much: narrowing the pedestal top (30 % → 26 %, so the graze was not only the rim) and a collision-aware IK seed bank (found no accurate clear branch on its own). Geometry was not the problem; the trajectory placement was.
General rule: verify the thing you will actually run. Coverage of the whole state space is a different and much weaker claim than correctness of the specific path, and it is the path that will be executed.

## A union that does not touch is still a success

tool_dock was modelled, rendered, dimensioned on a drawing sheet and counted in the mass budget with no latch on it. The three latch lugs — the entire reason that tool needs no seventh actuator — were placed inside the capture cone at a height where the bore had already opened to Ø25.8, so they sat 5.5 mm clear of any wall. CadQuery's .union() does not fail when the shapes do not touch; it returns a compound. Everything downstream treats a compound as a part. It would have come off the print bed as a probe plus three loose 19 mm³ crumbs.
The same class of error had already been caught once in this project — horn_adapter exported as two bodies because a box grew the wrong way — and the lesson was not generalised then. It is now: check_tool_fit.py counts len(shape.Solids()) for every tool part and fails on anything but 1, and cad/end_effector.py prints the solid count for each part as it exports.

Boolean success is not geometric contact. Ask for the solid count.

## Three defects in one interface, none of them visible

The docking pair was checked, part by part, and passed. Checked as a pair, it could not have worked at all:
1. the probe's latch lugs were not attached to the probe (above);
2. the target's capture groove was cut 3.30 mm deep into a 1.65 mm wall, which is not a groove but a parting cut — it severed the spigot tip, and the three entry slots then chopped what was left into three loose arcs;
3. even with both parts whole, the capture cone was 16 mm deep and the spigot 10 mm tall, so the cone mouth grounded on the target flange while the tip was still 6 mm short of the throat. Probe and target fouled at every insertion depth and every roll angle.
Two of those three look right in a render. The third is invisible in any single-part view, because it is a relationship between two parts, and no drawing of either part contains it. What found them was asking the geometry questions a picture cannot answer: how many solids are you, what is left of the wall after this cut, and drive one mesh onto the other and tell me what touches. The mate is now simulated through all five states — half inserted, seated, rolled to latch, pulled while latched (must catch), rolled back (must release) — and the capture envelope is measured by sweeping the probe sideways until it fouls, rather than quoted from the cone diameters.

A part that passes on its own tells you nothing about the joint it belongs to. Test the mate, not the parts.

## A drawing that asserts a defect the part no longer has

Three three-view sheets carried a bold red banner reading NO Ø42.00 BEARING POCKET. The banner came from a hardcoded list of part names, written when the audit first found those pockets missing. They were fixed the next day. The banner went on claiming the defect — in red, on the sheets someone prints from.
This is the J6 pilot error pointing the other way. A drawing that asserts a feature the part does not have is dangerous; a drawing that asserts a defect the part does not have is the same failure, and costs the same thing: it destroys the reader's ability to trust any stamp on any sheet. The banner now reads the pocket count out of the STEP.

Never hardcode a part's status. Status is a question you ask the geometry, every time you draw it.

## The same physical quantity, two different numbers, in two documents

Every drawing sheet quoted its part's mass at 55 % fill while the mass budget, the pre-print gate and every report used 90 % — so the sheets under-quoted every part by 39 %. The 0.55 was left over from before we established that a 2.4 mm wall at four perimeters and a 0.6 mm nozzle prints solid, and that applying an infill discount to geometry already modelled hollow counts the hollowing twice.
Nothing failed. Both numbers were internally consistent within their own document. That is what makes this the hard kind: it can only be caught by comparing two documents that nobody has any reason to read side by side. mass_of() now takes its fill from params.MASS_FILL, the same constant the budget uses.

If a number appears in two places, one of them is a copy, and copies rot.

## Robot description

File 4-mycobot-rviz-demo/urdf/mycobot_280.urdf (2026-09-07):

<?xml version="1.0"?>
<!--
  myCobot 280 - kinematic URDF reconstructed from "myCobot 280 URDF Joint
  Specifications" (PDF in this folder). Joint origins / axes / limits are taken
  verbatim from that document. Link visuals are simple cylinders generated to
  span each link vector so the arm is recognizable in RViz; they are cosmetic
  and carry no inertial/collision data (this model is for kinematics + RViz only).
  root link = link1 (base), end-effector frame = gripper_base.
-->
<robot name="mycobot_280">

  <material name="grey">  <color rgba="0.3 0.3 0.3 1.0"/></material>
  <material name="orange"><color rgba="0.9 0.5 0.1 1.0"/></material>
  <material name="blue">  <color rgba="0.1 0.3 0.8 1.0"/></material>

  <!-- ===== Links ===== -->

  <!-- link1 : base. Vertical cylinder up to joint 1 (h = 0.13156) -->
  <link name="link1">
    <visual>
      <origin rpy="0 0 0" xyz="0 0 0.06578"/>
      <geometry><cylinder radius="0.035" length="0.13156"/></geometry>
      <material name="grey"/>
    </visual>
  </link>

  <!-- link2 : near-zero offset to joint 2 -> small marker box -->
  <link name="link2">
    <visual>
      <origin rpy="0 0 0" xyz="0 0 0"/>
      <geometry><box size="0.05 0.05 0.04"/></geometry>
      <material name="orange"/>
    </visual>
  </link>

  <!-- link3 : cylinder along -X (h = 0.1104) -->
  <link name="link3">
    <visual>
      <origin rpy="0 1.5708 0" xyz="-0.0552 0 0"/>
      <geometry><cylinder radius="0.028" length="0.1104"/></geometry>
      <material name="blue"/>
    </visual>
  </link>

  <!-- link4 : cylinder along (-0.096, 0, 0.06062), |v| = 0.11349 -->
  <link name="link4">
    <visual>
      <origin rpy="0 -1.0070 0" xyz="-0.048 0 0.03031"/>
      <geometry><cylinder radius="0.024" length="0.11349"/></geometry>
      <material name="orange"/>
    </visual>
  </link>

  <!-- link5 : cylinder along -Y (h = 0.07318) -->
  <link name="link5">
    <visual>
      <origin rpy="1.5708 0 0" xyz="0 -0.03659 0"/>
      <geometry><cylinder radius="0.022" length="0.07318"/></geometry>
      <material name="blue"/>
    </visual>
  </link>

  <!-- link6 : cylinder along +Y (h = 0.0456) -->
  <link name="link6">
    <visual>
      <origin rpy="1.5708 0 0" xyz="0 0.0228 0"/>
      <geometry><cylinder radius="0.020" length="0.0456"/></geometry>
      <material name="orange"/>
    </visual>
  </link>

  <!-- link6_flange : short cylinder along +Z (h = 0.034) -->
  <link name="link6_flange">
    <visual>
      <origin rpy="0 0 0" xyz="0 0 0.017"/>
      <geometry><cylinder radius="0.018" length="0.034"/></geometry>
      <material name="grey"/>
    </visual>
  </link>

  <!-- gripper_base : end-effector marker -->
  <link name="gripper_base">
    <visual>
      <origin rpy="0 0 0" xyz="0 0 0.01"/>
      <geometry><box size="0.03 0.03 0.02"/></geometry>
      <material name="blue"/>
    </visual>
  </link>

  <!-- ===== Joints (origins/axes/limits verbatim from the PDF) ===== -->

  <joint name="link1_to_link2" type="revolute">
    <axis xyz="0 0 1"/>
    <limit effort="56.0" lower="-2.879793" upper="2.879793" velocity="2.792527"/>
    <parent link="link1"/>
    <child link="link2"/>
    <origin rpy="0 0 1.5707963267948966" xyz="0 0 0.13156"/>
  </joint>

  <joint name="link2_to_link3" type="revolute">
    <axis xyz="0 0 1"/>
    <limit effort="56.0" lower="-2.879793" upper="2.879793" velocity="2.792527"/>
    <parent link="link2"/>
    <child link="link3"/>
    <origin rpy="1.5707963267948966 0 -1.5707963267948966" xyz="0 0 -0.001"/>
  </joint>

  <joint name="link3_to_link4" type="revolute">
    <axis xyz="0 0 1"/>
    <limit effort="56.0" lower="-2.879793" upper="2.879793" velocity="2.792527"/>
    <parent link="link3"/>
    <child link="link4"/>
    <origin rpy="0 0 0" xyz="-0.1104 0 0"/>
  </joint>

  <joint name="link4_to_link5" type="revolute">
    <axis xyz="0 0 1"/>
    <limit effort="56.0" lower="-2.879793" upper="2.879793" velocity="2.792527"/>
    <parent link="link4"/>
    <child link="link5"/>
    <origin rpy="0 0 -1.5707963267948966" xyz="-0.096 0 0.06062"/>
  </joint>

  <joint name="link5_to_link6" type="revolute">
    <axis xyz="0 0 1"/>
    <limit effort="56.0" lower="-2.879793" upper="2.879793" velocity="2.792527"/>
    <parent link="link5"/>
    <child link="link6"/>
    <origin rpy="1.5707963267948966 -1.5707963267948966 0" xyz="0 -0.07318 0"/>
  </joint>

  <joint name="link6_to_link6_flange" type="revolute">
    <axis xyz="0 0 1"/>
    <limit effort="56.0" lower="-3.05" upper="3.05" velocity="2.792527"/>
    <parent link="link6"/>
    <child link="link6_flange"/>
    <origin rpy="-1.5707963267948966 0 0" xyz="0 0.0456 0"/>
  </joint>

  <joint name="link6_flange_to_gripper_base" type="fixed">
    <parent link="link6_flange"/>
    <child link="gripper_base"/>
    <origin rpy="1.579 0 0" xyz="0 0 0.034"/>
  </joint>

</robot>

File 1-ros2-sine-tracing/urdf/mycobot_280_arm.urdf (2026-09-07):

<?xml version='1.0' encoding='utf-8'?>
<robot name="mycobot_280">
  <link name="world" />
  <joint name="virtual_joint" type="fixed">
    <parent link="world" />
    <child link="base_link" />
    <origin rpy="0 0 0" xyz="0 0 0" />
  </joint>
  <link name="base_link">
    <inertial>
      <origin rpy="0 0 0" xyz="0 0 0.0" />
      <mass value="0.33" />
      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
    </inertial>
    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
  </link>
  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
  <link name="link1">
    <inertial>
      <origin rpy="0 0 0" xyz="0 0 0.0" />
      <mass value="0.12" />
      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
    </inertial>
    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
  </link>
  <link name="link2">
    <inertial>
      <origin rpy="0 0 0" xyz="0 0 0.0" />
      <mass value="0.19" />
      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
    </inertial>
    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
  </link>
  <link name="link3">
    <inertial>
      <origin rpy="0 0 0" xyz="0 0 0.0" />
      <mass value="0.16" />
      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
    </inertial>
    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
  </link>
  <link name="link4">
    <inertial>
      <origin rpy="0 0 0" xyz="0 0 0.0" />
      <mass value="0.124" />
      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
    </inertial>
    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
  </link>
  <link name="link5">
    <inertial>
      <origin rpy="0 0 0" xyz="0 0 0.0" />
      <mass value="0.11" />
      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
    </inertial>
    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
  </link>
  <link name="link6">
    <inertial>
      <origin rpy="0 0 0" xyz="0 0 0.0" />
      <mass value="0.0739" />
      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
    </inertial>
    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
  </link>
  <link name="link6_flange">
    <inertial>
      <origin rpy="0 0 0" xyz="0 0 0.0" />
      <mass value="0.035" />
      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
    </inertial>
    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
  </link>
  <joint name="base_link_to_link1" type="fixed">
    <parent link="base_link" />
    <child link="link1" />
    <origin rpy="0 0 0" xyz="0 0 0" />
  </joint>
  <joint name="link1_to_link2" type="revolute">
    <axis xyz="0 0 1" />
    <limit effort="56.0" lower="-2.879793" upper="2.879793" velocity="2.792527" />
    <parent link="link1" />
    <child link="link2" />
    <origin rpy="0 0 1.5707963267948966" xyz="0 0 0.13156" />
    <dynamics damping="0.0" friction="0.0" />
  </joint>
  <joint name="link2_to_link3" type="revolute">
    <axis xyz="0 0 1" />
    <limit effort="56.0" lower="-2.879793" upper="2.879793" velocity="2.792527" />
    <parent link="link2" />
    <child link="link3" />
    <origin rpy="0 1.5707963267948966 -1.5707963267948966" xyz="0 0 -0.001" />
    <dynamics damping="0.0" friction="0.0" />
  </joint>
  <joint name="link3_to_link4" type="revolute">
    <axis xyz="0 0 1" />
    <limit effort="56.0" lower="-2.879793" upper="2.879793" velocity="2.792527" />
    <parent link="link3" />
    <child link="link4" />
    <origin rpy="0 0 0" xyz="-0.1104 0 0" />
    <dynamics damping="0.0" friction="0.0" />
  </joint>
  <joint name="link4_to_link5" type="revolute">
    <axis xyz="0 0 1" />
    <limit effort="56.0" lower="-2.879793" upper="2.879793" velocity="2.792527" />
    <parent link="link4" />
    <child link="link5" />
    <origin rpy="0 0 -1.5707963267948966" xyz="-0.096 0 0.06062" />
    <dynamics damping="0.0" friction="0.0" />
  </joint>
  <joint name="link5_to_link6" type="revolute">
    <axis xyz="0 0 1" />
    <limit effort="56.0" lower="-2.879793" upper="2.879793" velocity="2.792527" />
    <parent link="link5" />
    <child link="link6" />
    <origin rpy="1.5707963267948966 -1.5707963267948966 0" xyz="0 -0.07318 0" />
    <dynamics damping="0.0" friction="0.0" />
  </joint>
  <joint name="link6_to_link6_flange" type="revolute">
    <axis xyz="0 0 1" />
    <limit effort="56.0" lower="-3.05" upper="3.05" velocity="2.792527" />
    <parent link="link6" />
    <child link="link6_flange" />
    <origin rpy="-1.5707963267948966 0 0" xyz="0 0.0456 0" />
    <dynamics damping="0.0" friction="0.0" />
  </joint>
  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
  <ros2_control name="RobotSystem" type="system">
    <hardware>
    </hardware>
    <joint name="link1_to_link2">
      <command_interface name="position">
        <param name="min">-2.879793</param>
        <param name="max">2.879793</param>
      </command_interface>
      <state_interface name="position" />
    </joint>
    <joint name="link2_to_link3">
      <command_interface name="position">
        <param name="min">-2.879793</param>
        <param name="max">2.879793</param>
      </command_interface>
      <state_interface name="position" />
    </joint>
    <joint name="link3_to_link4">
      <command_interface name="position">
        <param name="min">-2.879793</param>
        <param name="max">2.879793</param>
      </command_interface>
      <state_interface name="position" />
    </joint>
    <joint name="link4_to_link5">
      <command_interface name="position">
        <param name="min">-2.879793</param>
        <param name="max">2.879793</param>
      </command_interface>
      <state_interface name="position" />
    </joint>
    <joint name="link5_to_link6">
      <command_interface name="position">
        <param name="min">-2.879793</param>
        <param name="max">2.879793</param>
      </command_interface>
      <state_interface name="position" />
    </joint>
    <joint name="link6_to_link6_flange">
      <command_interface name="position">
        <param name="min">-3.05</param>
        <param name="max">3.05</param>
      </command_interface>
      <state_interface name="position" />
    </joint>
  </ros2_control>
</robot>

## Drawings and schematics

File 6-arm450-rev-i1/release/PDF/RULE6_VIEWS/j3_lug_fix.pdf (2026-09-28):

## J3 fork p1 -- spring lugs on the round cheek tops: rev I (released) vs rev I.1 (fixed)

section in the cheek plane through each lug (world y = +20.75 / -20.75), world x across, world z up

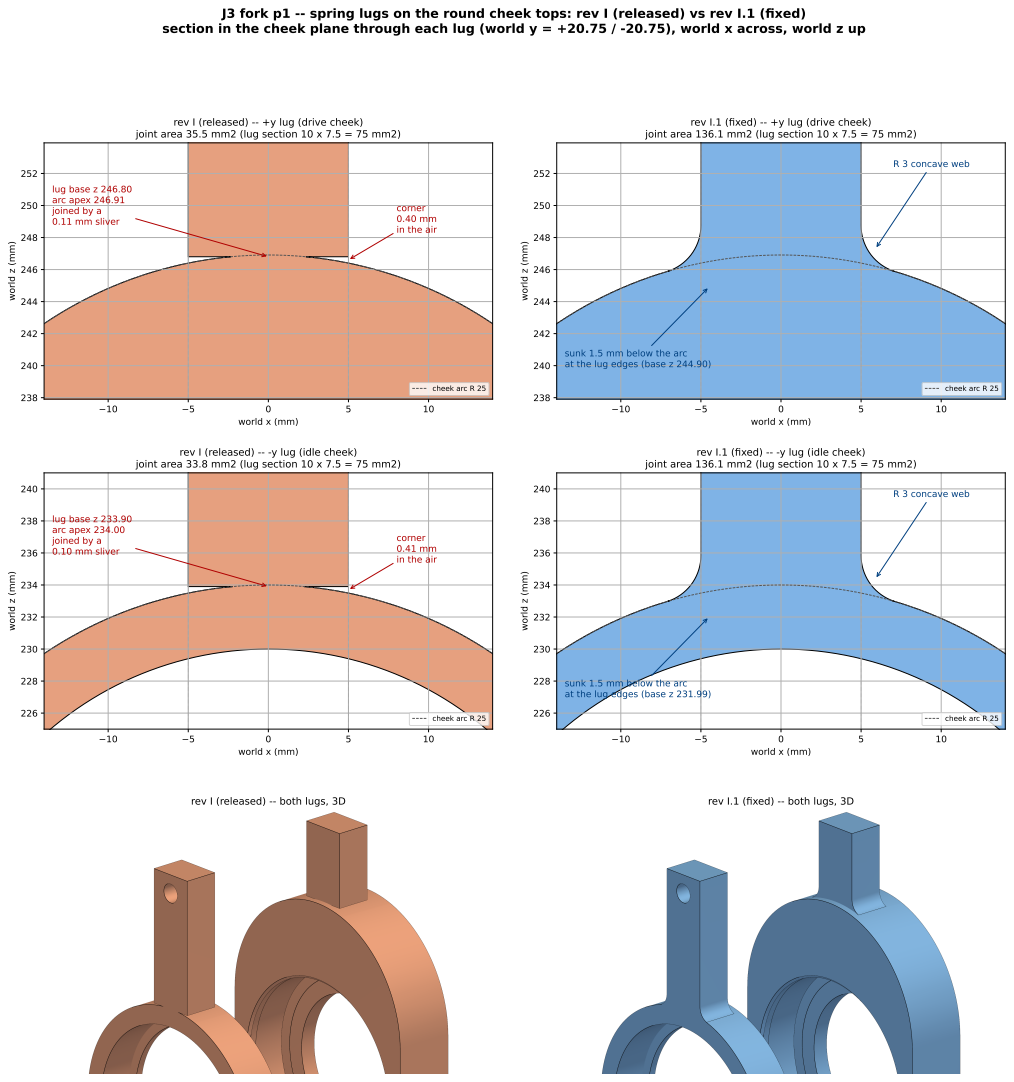
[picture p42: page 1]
world x (mm); world z (mm); cheek arc R 25; lug base z 233.90; R 3 concave web; rev I (released) -- both lugs, 3D; rev I.1 (fixed) -- both lugs, 3D

rev I (released) -- +y lug (drive cheek)
joint area 35.5 mm2 (lug section 10 x 7.5 = 75 mm2)

rev I.1 (fixed) -- +y lug (drive cheek)

joint area 136.1 mm2 (lug section 10 x 7.5 = 75 mm2)

R 3 concave web

lug base z 246.80 arc apex 246.91 | corner
joined by a 0.11 mm sliver | 0.40 mm in the air

sunk 1.5 mm below the arc
at the lug edges (base z 244.90)

rev I (released) -- -y lug (idle cheek)

rev I.1 (fixed) -- -y lug (idle cheek)

joint area 33.8 mm2 (lug section 10 x 7.5 = 75 mm2)

arc apex 234.00 joined by a 0.10 mm sliver | corner 0.41 mm

in the air

at the lug edges (base z 231.99)

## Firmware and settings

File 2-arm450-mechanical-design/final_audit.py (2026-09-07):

"""
Final pre-print audit — the checks the gate does NOT do.

preflight.py verifies that the DESIGN is right: geometry present, margins held,
paths clear, model matching. This asks a different question: **can this actually
be printed, and is there anything in the output folder that would be printed by
mistake?**

Those are the failure modes left on the day of the print, and none of them is a
design error:

  * a feature thinner than two extrusion widths, which the slicer silently drops
  * a hole smaller than the nozzle, which comes out solid
  * an overhang the part cannot bridge in the stated orientation
  * a part that does not fit the build volume
  * a STEP and an STL that disagree, so the drawing and the print differ
  * a SUPERSEDED part sitting in the same folder as the live ones
"""
import json
import os
import sys

import numpy as np
import trimesh

HERE = os.path.dirname(os.path.abspath(__file__))
CAD = os.path.join(HERE, "output", "cad")
sys.path.insert(0, HERE)
sys.path.insert(0, os.path.join(HERE, "cad"))
from params import *          # noqa: F403,F401

from params import NOZZLE, EXTRUSION_W, LAYER_H     # noqa: E402
LINE_W = EXTRUSION_W
MIN_WALL = 2 * LINE_W         # 1.24 mm — below this a wall is not printable
LAYER = LAYER_H               # was hardcoded 0.28, which does not divide the
                              # 1.6 mm seam tongue. Read it from params.
BED = (250.0, 210.0, 210.0)   # a common consumer envelope; adjust to yours
OVERHANG_LIMIT = 50.0         # deg from vertical before support is wanted

# the parts that are actually printed, from BUY.md's print list
LIVE = [
    "link_half_tongue", "link_half_groove", "wrist_j4_housing", "wrist_j5_yoke",
    "wrist_j6_output", "horn_adapter", "shaft_clamp", "servo_collar",
    "turret_j1", "base", "fit_coupon",
    "tool_adapter", "tool_gripper", "gripper_jaw", "gripper_pinion",
    "tool_dock", "dock_target", "dock_target_sealed",
]
# generated for analysis or superseded by a later part — NOT to be printed
NOT_PRINTED = {
    "joint_shaft": "the Ø30 shaft is an ALUMINIUM TUBE, not printed (shaft_tube is its drawing)",
    "shaft_tube": "aluminium tube — a drawing of bought stock, not a print",
    "bearing_6806": "a model of a bought bearing",
    "bearing_yoke": "superseded by wrist_j5_yoke",
    "wrist_yoke_j5": "superseded by wrist_j5_yoke",
    "roll_module": "superseded by wrist_j4_housing / wrist_j6_output",
    "wrist": "superseded by the three integrated wrist parts",
    "tool_flange": "superseded — the flange is integral to wrist_j6_output",
    "arm450_parts_kit": "a layout of every part on one plate, for viewing",
    "arm450_assembly_home": "assembly render, not a part",
    "arm450_assembly_working": "assembly render, not a part",
    "arm450_assembly_exploded": "assembly render, not a part",
}

R = []


def chk(ok, name, det, hard=True):
    R.append((bool(ok), name, det, hard))
    return ok


def thickness_probe(name, m):
    """Minimum wall, by voxel medial axis — see wall_check.py.

    The first version of this used ray casting. This machine has no `rtree`, so
    every call raised, every part returned None, and the check reported PASS on
    ZERO measurements. That is worse than no check: it is a green tick standing
    in for an answer nobody has. A check that cannot run must say so.

    Large parts are skipped deliberately rather than silently: at a fine pitch a
    183 mm link is tens of millions of voxels, and its design wall is 2.4 mm,
    nowhere near the 1.24 mm floor. Skipped parts return None and are reported
    as NOT MEASURED, not as passing.
    """
    if max(m.extents) > 90.0:
        return None
    import wall_check as WC
    try:
        r = WC.wall(name, 0.30)
    except Exception:                                    # noqa: BLE001
        return None
    return None if r is None else r[0]


def overhang_area(m, up=(0, 0, 1)):
    """Fraction of surface area whose normal points DOWN by more than the
    overhang limit. High values mean the stated print orientation needs support
    on a face that carries load."""
    up = np.asarray(up, float)
    cosang = m.face_normals @ up
    lim = -np.cos(np.radians(90.0 - (90.0 - OVERHANG_LIMIT)))
    steep = cosang < -np.sin(np.radians(90.0 - OVERHANG_LIMIT))
    a = m.area_faces
    return float(a[steep].sum() / a.sum())


def main():
    print("=" * 84)
    print("ARM-450 — FINAL PRE-PRINT AUDIT")
    print(f"nozzle {NOZZLE} mm · line {LINE_W} mm · layer {LAYER} mm · "
          f"min printable wall {MIN_WALL:.2f} mm")
    print("=" * 84)

    VOL = json.load(open(os.path.join(CAD, "volumes.json")))
    stls = sorted(f[:-4] for f in os.listdir(CAD) if f.endswith(".stl"))

    # ---- 1. is anything in the folder that must NOT be printed? -----------
    print("\n1. WHAT IS IN THE OUTPUT FOLDER")
    unknown = [s for s in stls if s not in LIVE and s not in NOT_PRINTED]
    chk(not unknown, "every STL is either on the print list or explicitly not",
        f"{len(LIVE)} live, {len([s for s in stls if s in NOT_PRINTED])} "
        f"not-printed, {len(unknown)} unaccounted"
        + (f" -> {unknown}" if unknown else ""))
    missing = [p for p in LIVE if p not in stls]
    chk(not missing, "every part on the print list has an STL",
        f"{len(LIVE)}/{len(LIVE)} present" if not missing else f"MISSING {missing}")
    print(f"\n   NOT TO BE PRINTED — {len(NOT_PRINTED)} files sit beside the live ones:")
    for k, why in NOT_PRINTED.items():
        if k in stls:
            print(f"     {k:24s} {why}")

    # ---- 2. per-part printability ----------------------------------------
    print("\n2. PRINTABILITY, PART BY PART")
    print(f"   {'part':22s} {'envelope mm':>22s} {'min wall':>9s} {'overhang':>9s} "
          f"{'bodies':>7s} {'STEP vs STL':>12s}")
    print("   " + "-" * 86)
    thin, big, multi, mismatch, hangs, unmeasured = [], [], [], [], [], []
    for name in LIVE:
        m = trimesh.load(os.path.join(CAD, name + ".stl"), force="mesh")
        ex = m.extents
        t = thickness_probe(name, m)
        oh = overhang_area(m)
        nb = len(m.split(only_watertight=False)) if m.body_count > 1 else 1
        vstep = VOL.get(name)
        dv = abs(m.volume - vstep) / vstep * 100 if vstep else float("nan")
        fits = all(ex[i] <= BED[i] for i in range(3)) or \
            all(sorted(ex)[i] <= sorted(BED)[i] for i in range(3))
        if t is None:
            unmeasured.append((name, None))
        elif t < MIN_WALL:
            thin.append((name, t))
        if not fits:
            big.append(name)
        if nb > 1:
            multi.append((name, nb))
        if vstep and dv > 1.0:
            mismatch.append((name, dv))
        if oh > 0.30:
            hangs.append((name, oh))
        print(f"   {name:22s} {ex[0]:6.1f}×{ex[1]:6.1f}×{ex[2]:6.1f} "
              f"{(f'{t:8.2f}' if t else '      --')} {oh*100:8.1f}% {nb:7d} "
              f"{dv:11.2f}%")

    n_meas = sum(1 for p_ in LIVE if p_ not in [x[0] for x in unmeasured])
    chk(not thin, "no measured feature below the printable wall",
        f"{len(thin)} thin: {thin}" if thin else
        f"{n_meas} parts measured, all ≥ {MIN_WALL:.2f} mm "
        f"(2 lines at a {NOZZLE} mm nozzle)")
    chk(not unmeasured, "every part had its wall thickness measured",
        "all measured" if not unmeasured else
        f"NOT MEASURED (too large to voxelise at 0.30 mm): "
        f"{[x[0] for x in unmeasured]} — design wall 2.4–3.0 mm, "
        f"2x the floor, but not verified here", hard=False)
    chk(not big, "every part fits the build volume",
        f"{BED[0]:.0f}×{BED[1]:.0f}×{BED[2]:.0f} mm" if not big else f"TOO BIG {big}")
    chk(not multi, "every part is a single connected body",
        "no loose fragments" if not multi else f"MULTI-BODY {multi}")
    chk(not mismatch, "STL agrees with the STEP it was exported from",
        "all within 1 %" if not mismatch else f"DISAGREE {mismatch}")
    chk(not hangs, "no part is mostly overhang in its print orientation",
        f"worst {max((o for _n, o in hangs), default=0)*100:.0f} %" if hangs
        else "all under 30 % downward-facing area", hard=False)

    # ---- 3. holes vs the fasteners that go in them ------------------------
    print("\n3. HOLES vs FASTENERS")
    import audit_parts as AP
    FAST = {M3_CLEAR: "M3 clearance", 2.7: "M3 self-tap / insert pilot",
            M2_5_CLEAR if "M2_5_CLEAR" in dir() else 2.9: "M2.5 clearance",
            4.0: "Ø4 heat-set insert", 3.4: "M3 thumbscrew"}
    small = []
    for name in LIVE:
        for g in AP.cylinders(os.path.join(CAD, name + ".step")):
            if g["dia"] < NOZZLE * 2:
                small.append((name, round(g["dia"], 2)))
    chk(not small, "no hole smaller than two extrusion widths",
        f"smallest holes are ≥ {NOZZLE*2:.1f} mm" if not small
        else f"TOO SMALL {small[:6]}")

    # ---- 4. mass, from the final geometry --------------------------------
    print("\n4. MASS, RECOMPUTED FROM THE FINAL STEPs")
    qty = {"link_half_tongue": 2, "link_half_groove": 2, "horn_adapter": 6,
           "shaft_clamp": 2, "servo_collar": 2}
    printed = sum(VOL[p] * 1.29e-3 * MASS_FILL * qty.get(p, 1)
                  for p in LIVE if p in VOL and p not in
                  ("fit_coupon", "tool_adapter", "tool_gripper", "gripper_jaw",
                   "gripper_pinion", "tool_dock", "dock_target"))
    servos, brg, shafts, fast = 360.0, 134.0, 84.0, 202.0
    total = printed + servos + brg + shafts + fast
    print(f"   printed structure   {printed:7.1f} g")
    print(f"   servos (6)          {servos:7.1f} g")
    print(f"   bearings (12)       {brg:7.1f} g")
    print(f"   aluminium shafts    {shafts:7.1f} g")
    print(f"   fasteners, inserts  {fast:7.1f} g")
    print(f"   {'TOTAL':19s} {total:7.1f} g   of {MASS_BUDGET:.0f} g")
    chk(total <= MASS_BUDGET, "arm mass inside the hard ceiling",
        f"{total:.0f} g of {MASS_BUDGET:.0f} g, {MASS_BUDGET-total:.0f} g spare")

    # ---- 5. filament and time estimate -----------------------------------
    print("\n5. WHAT THE PRINT COSTS")
    v_live = sum(VOL[p] * MASS_FILL * qty.get(p, 1) for p in LIVE if p in VOL)
    grams = v_live * 1.29e-3
    metres = v_live / (np.pi * (1.75 / 2) ** 2) / 1000.0
    print(f"   filament            {grams:7.0f} g  ({metres:.0f} m of 1.75 mm)")
    print(f"   one 1 kg spool covers it with {1000-grams:.0f} g to spare")

    # ---- verdict ----------------------------------------------------------
    print("\n" + "=" * 84)
    for ok, name, det, hard in R:
        tag = " PASS " if ok else (" FAIL " if hard else " NOTE ")
        print(f"  [{tag}] {name:52s} {det}")
    bad = [r for r in R if not r[0] and r[3]]
    note = [r for r in R if not r[0] and not r[3]]
    print("=" * 84)
    print(f"  {len(R)-len(bad)-len(note)} passed, {len(note)} notes, {len(bad)} failures")
    print("=" * 84)
    return bad


if __name__ == "__main__":
    sys.exit(1 if main() else 0)

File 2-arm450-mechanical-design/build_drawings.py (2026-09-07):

"""
Build the ARM-450 parts & dimensions document.

Measures every STL in the user's Fusion folder, renders each part, assigns a
part number, and emits DRAWINGS.md -> output/ARM450_DRAWINGS.pdf.
"""

import os
import glob
import numpy as np
import trimesh
import matplotlib
matplotlib.use("Agg")
import matplotlib.pyplot as plt

from render_existing import paint

SRC = os.path.expanduser("~/Desktop/Robotic_arm_design")
HERE = os.path.dirname(os.path.abspath(__file__))
FIGS = os.path.join(HERE, "figures", "parts")
os.makedirs(FIGS, exist_ok=True)

RHO = 0.55e-3      # g/mm^3, PLA at ~35 % infill — estimate only

# part number, filename, group, function, status
CATALOGUE = [
    ("A-01", "base_p1.stl",            "Base",   "Lower base shell, D-profile", "keep"),
    ("A-02", "base_p2.stl",            "Base",   "Base cover / floor plate", "keep"),
    ("A-03", "Motor_mount_base.stl",   "Base",   "J1 servo mount, top-hat flange", "revise"),
    ("B-01", "link1_base.stl",         "Link",   "Upper-arm shell, lower half", "LENGTHEN"),
    ("B-02", "link1_cover.stl",        "Link",   "Upper-arm shell, upper half", "MISMATCH"),
    ("B-03", "link2_base.stl",         "Link",   "Forearm shell, lower half", "LENGTHEN"),
    ("B-04", "link2_cover.stl",        "Link",   "Forearm shell, upper half", "LENGTHEN"),
    ("B-05", "link1_base_1.1.stl",     "Link",   "Upper-arm shell rev 1.1 (longer)", "REJECT"),
    ("B-06", "link1_cover1.1.stl",     "Link",   "Upper-arm cover rev 1.1", "REJECT"),
    ("B-07", "link2_cover2.1.stl",     "Link",   "Forearm cover rev 2.1", "keep"),
    ("C-01", "J2_p1.stl",              "Joint",  "J2 shoulder yoke, driven side", "revise"),
    ("C-02", "J2_p2.stl",              "Joint",  "J2 shoulder yoke, idler side", "revise"),
    ("C-03", "J4_p1.stl",              "Joint",  "J4 yoke, driven side", "revise"),
    ("C-04", "J4_p2.stl",              "Joint",  "J4 yoke, idler side", "revise"),
    ("C-05", "Motor_housing_new.stl",  "Joint",  "Elbow motor housing", "keep"),
    ("D-01", "wrist_p1.stl",           "Wrist",  "Wrist body, driven side", "keep"),
    ("D-02", "wrist_p2.stl",           "Wrist",  "Wrist body, idler side", "keep"),
    ("E-01", "Motor_mount_J1.stl",     "Mount",  "J1 servo mount", "REDESIGN"),
    ("E-02", "Motor_mount_J2.stl",     "Mount",  "J2 servo mount", "REDESIGN"),
    ("E-03", "Motor_mount_wrist.stl",  "Mount",  "Wrist servo mount", "REDESIGN"),
    ("E-04", "Motor_mount.stl",        "Mount",  "Generic servo mount", "REDESIGN"),
    ("E-05", "Motor_mount_changed_ 2mm_length.stl", "Mount",
                                        "Servo mount, +2 mm variant", "REDESIGN"),
    ("F-01", "Motor_fixer_j2_p1.stl",  "Fixer",  "J2 servo clamp, 6 mm plate", "FAILS"),
    ("F-02", "Motor_fixer_j2_p2.stl",  "Fixer",  "J2 servo clamp, 4 mm plate", "FAILS"),
    ("F-03", "motor fixer.stl",        "Fixer",  "Servo clamp, U-channel", "FAILS"),
    ("F-04", "motor fixer_wrist.stl",  "Fixer",  "Wrist servo clamp", "FAILS"),
    ("G-01", "ST3215.stl",             "COTS",   "Feetech ST3215 serial-bus servo", "COTS"),
    ("G-02", "thrust ball bearing.stl", "COTS",  "Thrust ball bearing Ø42", "REPLACE"),
    ("G-03", "pin.stl",                "Tool",   "Grasp pin / end effector", "keep"),
]

STATUS_NOTE = {
    "keep": "Carry forward unchanged.",
    "revise": "Minor revision — fillets and bearing seats.",
    "LENGTHEN": "Lengthen to 145 mm joint-to-joint.",
    "MISMATCH": "Envelope does not pair with its base shell — check before reuse.",
    "REJECT": "Unequal link length; creates a dead zone and exceeds 450 mm.",
    "REDESIGN": "Redesign as a full-perimeter collar; current form is understrength.",
    "FAILS": "Fails at servo stall torque. Do not reprint as-is.",
    "COTS": "Commercial off-the-shelf, not printed.",
    "REPLACE": "Replace with a spaced, preloaded pair of deep-groove bearings.",
}


def measure(path):
    m = trimesh.load(path, force="mesh")
    e = m.extents
    V = m.volume if m.is_watertight and m.volume > 0 else float("nan")
    A = m.area
    t = 2 * V / A if V == V else float("nan")
    return m, e, V, A, t


def render_grid(entries, out, title, cols=4):
    rows = int(np.ceil(len(entries) / cols))
    fig = plt.figure(figsize=(3.6 * cols, 3.5 * rows))
    fig.patch.set_facecolor("white")
    for i, (pn, fn, grp, fun, st) in enumerate(entries):
        p = os.path.join(SRC, fn)
        ax = fig.add_subplot(rows, cols, i + 1)
        if not os.path.exists(p):
            ax.axis("off")
            continue
        m = trimesh.load(p, force="mesh")
        col = (0.80, 0.45, 0.38) if st in ("FAILS", "REDESIGN", "REJECT", "REPLACE") \
            else (0.62, 0.70, 0.79)
        paint(ax, m, 38, 24, base=col)
        e = m.extents
        ax.set_title(f"{pn}  {fn.replace('.stl','')}\n"
                     f"{e[0]:.1f} × {e[1]:.1f} × {e[2]:.1f} mm",
                     fontsize=8.6, fontweight="bold", color="#1b2733")
    fig.suptitle(title, fontsize=14, fontweight="bold", color="#1b2733", y=0.995)
    fig.tight_layout(rect=(0, 0, 1, 0.96))
    fig.savefig(out, dpi=115, facecolor="white")
    plt.close(fig)
    print(f"wrote {out}")
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

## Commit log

2026-09-07 Engineering portfolio: ROS 2 kinematics, ARM-450 design, hardware bring-up
    Four projects presented for an industry audience:
    1. myCobot 280 sine tracing - from-scratch modified-DH FK, velocity
    propagation Jacobian and DLS IK, verified to ~1e-15 m vs the URDF
    2. ARM-450 - clean-sheet 6-DOF arm, parametric CAD in Python, 450 mm /
    1365 g, 60-check pre-print verification gate
    3. ESP32 + STS3215 serial-bus servo bring-up, from dead bus to motion
    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
    [arm450.urdf, arm450_assembly_exploded.step, arm450_assembly_home.step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]
2026-09-07 Add ARM-450 ROS 2 packages and the ROS 2 learning progression
    arm450_description (URDF + meshes) and arm450_sine show the designed arm
    actually loaded and driven in ROS 2, not only drawn.
    5-ros2-learning-progression keeps the six packages that led to the verified
    solver, in order and unedited: publisher/subscriber, forward kinematics, a
    first sine attempt, the rewrite after it drifted, a modular restructure,
    then Rsine.
    [arm450.urdf, arm450_meshes.urdf, base_link.stl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]
2026-09-28 Add ARM-450 rev I.1: printable release, verification logs, kinematics
    Project 6: the rev I.1 release (STL print set, STEP/URDF/Fusion/SolidWorks
    editable CAD, Fusion design-tree scripts, PDFs, per-check logs), the
    generator and verification scripts, and the kinematics package (DH from
    the CAD, FK/IK/Jacobian, workspace, manipulability, timed sine, ROS 2 demo).
    Project 2 is marked as the first concept.
    [01_base_x1.step, 01_base_x1.stl, 01_base_x1_released.step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]
2026-09-28 Add videos: myCobot Gazebo/RViz sessions, ARM-450 sine, print timelapse
    13 clips in date order with a README describing each one. The screen
    recordings are cropped to the Gazebo/RViz windows; the 30 June session is
    cut to 60 s. Linked from a new Videos section in the main README.
